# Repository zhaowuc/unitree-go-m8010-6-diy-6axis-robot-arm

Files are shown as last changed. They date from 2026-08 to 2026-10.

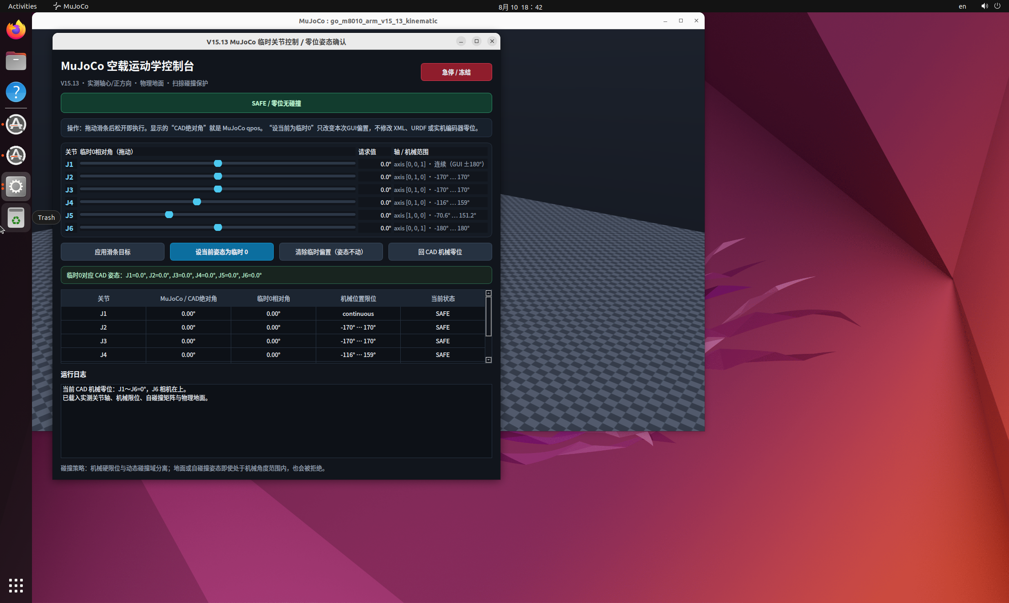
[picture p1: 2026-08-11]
mujoco_kinematic_v1/previews/gui_vm_desktop.png

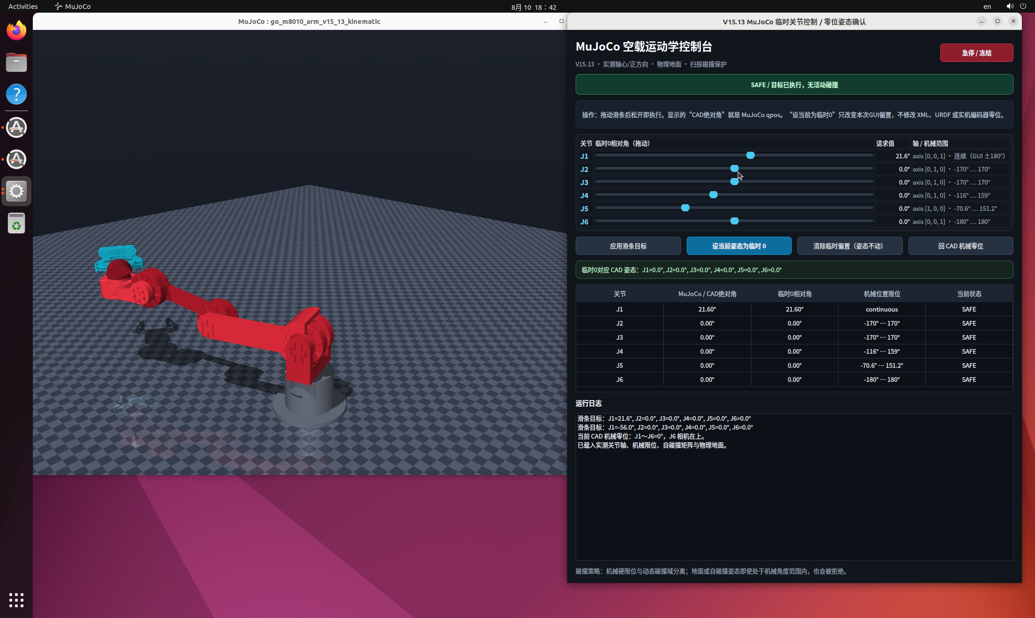
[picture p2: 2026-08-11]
mujoco_kinematic_v1/previews/gui_vm_desktop_arranged.png

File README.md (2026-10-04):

# 基于宇树go-m8010-6关节电机的自组6轴机械臂

这是 GO-M8010-6 + DM-G6220 六自由度机械臂的长期主工程。当前主线为 V15.13，仓库保留机械设计、几何与碰撞验收、仿真集成资产以及后续 ROS 2 / MoveIt 2 开发所需的源文件。

## 主要内容

- FreeCAD 完整机械装配、刚性 Link 拆分工程和 STEP/STL 模型；
- J1～J6 真实关节中心、轴向、零位与机械位置限位定义；
- MuJoCo 空载运动学模型、物理网格地面、自碰撞守卫和临时关节控制界面；
- ROS 2 工作区、URDF/Xacro、视觉与碰撞网格；
- MoveIt 2 配置、关节限位和自碰撞策略；
- 装配预览、实物运动证据、几何/碰撞 QA 报告和复现工具。

## 机械与运动学约定

- 软件运动学保持六个机械自由度：`J1`～`J6`。
- `J2` 是一个机械自由度，由两台镜像安装的 GO-M8010-6 共同驱动；两台电机不是两个独立运动学关节，软件中仍只有一个 `J2`。
- `world -> base_link -> J1 -> link1 -> J2 -> link2 -> J3 -> link3 -> J4 -> link4 -> J5 -> link5 -> J6 -> link6 -> fixed -> gripper`。
- `tool_reference` 是 J6 输出/夹爪安装中心。
- `tcp_nominal` 是 `ClosureAngle=0°` 时左右硅胶有效夹持面面积质心的中点，位于 gripper 局部坐标：

  ```text
  [-0.001187726400, 0.000060729026, 0.092493513872] m
  ```

  当前只在 MuJoCo 中作为固定名义参考点使用；动态 TCP、ROS TF 和 MoveIt TCP 尚未实现。

## 目录

- `机械臂完整装配_六轴_相机上置机械零位_深度复核_v15_13.FCStd`：当前完整装配。
- `机械臂完整装配_六轴_刚性Link拆分_v15_13.FCStd`：刚性 Link 拆分工程。
- `mujoco_kinematic_v1/`：当前可运行的 MuJoCo 空载运动学版本。
- `rigid_links_v15_13/`：ROS 2 / MuJoCo 刚性 Link 网格与导出定义。
- `完整工程_V15_13_交付/ros2_ws/`：ROS 2、URDF/Xacro 与 MoveIt 2 工程。
- `完整工程_V15_13_交付/source_models/`：夹爪和相机源模型。
- `evidence/`、`装配预览图/`、`三视图资产_world/`：验收证据与展示资产。
- `完整工程_V15_13_交付/tools/`、`mujoco_kinematic_v1/windows_export_tools/`：构建、导出和验证工具。

## 当前工程边界

当前 MuJoCo 版本首先保证外形、尺寸、相对位置、J1～J6 运动学、机械限位和自碰撞关系。质量、质心、惯量、速度、力矩、阻尼、摩擦和负载参数仍需依据实测数据完善，不应把现有占位值用于最终动力学或实机力矩控制。

后续计划包括重力补偿、动态 TCP、ROS 2 控制链、MoveIt 2 规划完善以及 Gemini Pro 视觉抓取。

## 大型文件

FCStd、STEP/STP、STL、OBJ、DAE、GLB、MP4 等机械与媒体资产由 Git LFS 管理。克隆后请确保已安装 Git LFS，并执行：

```bash
git lfs install
git lfs pull
```

## 开源许可证

本项目采用 [MIT 许可证](LICENSE)。第三方模型、依赖和素材遵循各自的许可证。

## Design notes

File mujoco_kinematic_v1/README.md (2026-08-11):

# V15.13 MuJoCo 空载运动学版

本版只验收四项：

1. `base_link`、`link1`～`link6`、`gripper` 的外形、尺寸和零位相对位置；
2. J1～J6 真实旋转中心；
3. J1～J6 轴向与右手法则正方向；
4. 机械位置限位、非相邻刚体自碰撞和物理地面碰撞。

主模型：`go_m8010_arm_v15_13_kinematic.xml`

拓扑固定为：

`world -> base_link -> J1 -> link1 -> J2 -> link2 -> J3 -> link3 -> J4 -> link4 -> J5 -> link5 -> J6 -> link6 -> fixed -> gripper`

J6 为有限旋转 `[-π,+π]`，`J6=0` 时 Gemini Pro 相机在上。夹爪在这个六轴首版中冻结于已验证的零位，以 fixed body 连接到 `link6`。

## 最终验证结果

- MuJoCo：`3.11.0`，模型可实际编译；
- 拓扑：`nq=6`、`nv=6`，J1～J6 顺序正确；
- Link 零位位姿、关节中心、轴向和 `+0.5°` 右手法则见证点全部通过；
- 视觉网格未减面，原三角面集保留；仅为 MuJoCo 单 STL `200,000` 面上限分成 45 个块；
- 24 个 FreeCAD 审计碰撞代理生成 961 个米制凸体；
- 保存零位的完整 231 对运行时矩阵无碰撞；
- 原 503 姿态“V15.13 末端变更相关碰撞对”回归完全一致；随机 150 位姿仍仅索引 `43, 73, 75, 83, 87` 碰撞，与 FreeCAD/VTK 基准一致；
- 新增全运行时碰撞对的逐轴 5° 深度扫描（386 点）：J1、J6 全清空；J2 有 31 个对地禁用点；J3 有 29 个对地、9 个自碰撞点（35 个姿态并集）；J4 有 12 个对地、1 个自碰撞点；J5 有 2 个自碰撞点；这些点均被运行时守卫及扫掠路径检查 fail-closed 拦截；
- 网格地面位于 `Z=-0.090 m`，由 `base_link` 最低支承面精确导出。固定底座不与地面求解，所有运动 Link 启用地面碰撞；
- 完整报告：`QA_MUJOCO_V15_13_空载运动学版.json`。
- 逐轴深度报告：`QA_MUJOCO_V15_13_逐轴运动语义与地面复核.json`。

Link 局部包围尺寸（mm）：

| Link | X | Y | Z |
|---|---:|---:|---:|
| base_link | 176.921 | 176.866 | 100.000 |
| link1 | 96.500 | 137.600 | 149.190 |
| link2 | 307.096 | 99.500 | 115.901 |
| link3 | 299.261 | 52.500 | 148.876 |
| link4 | 60.828 | 97.000 | 176.265 |
| link5 | 70.000 | 70.000 | 127.527 |
| link6 | 34.992 | 35.001 | 1.000 |
| gripper | 107.129 | 133.135 | 123.402 |

## Ubuntu 22.04 执行

```bash
source /home/codex/mujoco_arm_env/bin/activate
python build_model.py
python validate_model.py
python validate_joint_motion_semantics.py
MUJOCO_GL=egl python render_previews.py
```

交互查看：

```bash
DISPLAY=:1 XAUTHORITY=/run/user/1000/gdm/Xauthority \
  /home/codex/mujoco_arm_env/bin/python launch_viewer.py
```

单点限位/碰撞检查（角度制 J1～J6）：

```bash
python kinematic_guard.py 0 0 0 0 0 0
```

`KinematicGuard.check_swept_deg()` 以默认最大 `0.25°` 插值步长检查一段运动。

临时滑条 GUI（会同时打开可用鼠标旋转视角的 MuJoCo 窗口）：

```bash
DISPLAY=:1 XAUTHORITY=/run/user/1000/gdm/Xauthority MUJOCO_GL=glfw \
  /home/codex/mujoco_arm_env/bin/python temporary_joint_gui.py
```

GUI 中显示两套角度：

- `MuJoCo / CAD绝对角`：模型真实 `qpos`，以已核验 CAD 机械零位为 0；
- `临时0相对角`：本次 GUI 会话的滑条偏置。

先用滑条移动到安全姿态，再点“保存当前姿态为启动 0”，界面会明确显示该 GUI 启动 0 对应的六个 CAD 绝对角，并写入 `gui_default_zero.json`。再次打开 GUI 时，模型直接恢复到该姿态，六个相对滑条均为 0°。该操作不修改 MJCF、URDF、CAD 机械零位或实机编码器零位；“回 CAD 机械零位”只影响当前会话，不删除已保存的 GUI 启动 0。地面、自碰撞、机械限位或穿越不安全中间姿态时，目标会被拒绝并保持上一安全姿态。

当前几何精校后的 GUI 启动 0（CAD 绝对角）：`J1=-135.0°、J2=150.0°、J3=-74.402070913°、J4=-90.0°、J5=45.0°、J6=0.713491710°`。该解保留规整的 J1/J2/J4/J5，仅根据真实 J3、J4 轴心求解 J3，使 J3→J4 中心线竖直；再根据 Gemini Pro 碰撞代理的 102.896 mm 长轴求解 J6，使相机长边与物理地面平行，同时保持既有相机俯仰/观看分支。复算脚本为 `calibrate_gui_zero.py`，完整残差、限位、碰撞及扫掠结果见 `QA_MUJOCO_V15_13_GUI零位几何校准.json`。

如果从 FreeCAD 原始网格全量重建，再执行：

```bash
python prepare_assets.py
python prepare_visual_chunks.py
python build_model.py
python validate_model.py
python validate_joint_motion_semantics.py
```

`V15_13_自碰撞对矩阵契约.json` 是运行时/MoveIt ACM 的对级契约；`kinematic_guard.py` 会仅上报契约中有效的物理对，忽略同刚体、轴承座和设计接触。

## 物理边界

当前 `inertial` 仅为 MuJoCo 编译所需的数值占位，不是实测质量/质心/惯量。未实测速度、力矩、阻尼、摩擦及负载；不得将本版用于动力学、力矩控制或实机参数整定。

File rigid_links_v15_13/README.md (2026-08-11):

# V15 刚性 Link 拆分

本目录不是“整机一个 STL”。主机械臂按以下刚体链导出：

`world -> base_link -> J1 -> link1 -> J2 -> link2 -> J3 -> link3 -> J4 -> link4 -> J5 -> link5 -> J6 -> link6 -> fixed -> gripper`

- `visual/*.stl` 与 `collision/*.stl` 均在各自 Link 局部坐标系中，STL 数值单位为 mm。
- ROS 2 / MuJoCo 使用时 mesh scale 为 `0.001 0.001 0.001`。
- 每颗螺丝、垫圈和固定支架已经并入随动刚体，没有生成独立 Link。
- J1/J2 的完整 GO-M8010 STEP 已按工程中审计过的 BRep 固体编号拆成定子、输出转子和中性 B6808 显示件，未按外观猜测。
- `gripper.stl` 只包含与连接件、舵机壳体和固定框架相对静止的静态部分。
- 夹爪六个会相对运动的刚体位于 `gripper_internal_zero_reference/`；这些文件共用 `gripper` 零位坐标，仅用于后续建立夹爪内部关节，不得重新焊成一个刚体。
- `gripper_complete_zero_reference.stl` 只是零位总览，不能作为单个 URDF/MuJoCo 刚体。
- 质量、质心、惯量、速度/力矩上限、MuJoCo 设计接触排除和 tool0/TCP 尚无实测数据，未填写猜测值。

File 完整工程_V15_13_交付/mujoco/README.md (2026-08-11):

# MuJoCo V15.13 staging

关节树、轴、原点、J2～J6 位置限位和 visual/collision 网格已写入模板。J6 为 `hinge`，`ref=0` 时相机在上，`range=-π +π`。

模板中的质量、质心、完整惯量张量和摩擦参数均为 `__...__` 占位符，必须由实测/标定值替换；没有替换前不是可运行的动力学模型。不要让 MuJoCo 依据高细节网格默认密度猜惯量。组合动作仍需使用碰撞检测，因为独立关节限位的笛卡尔积包含自碰撞姿态。

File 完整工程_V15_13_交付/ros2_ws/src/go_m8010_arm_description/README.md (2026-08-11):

# go_m8010_arm_description V15.13

几何、真实关节轴、关节原点、零位和位置限位已经复核。J6 在 `0°` 时相机位于上侧，位置限位为 `[-π,+π]`。

`j*_effort_nm` 与 `j*_velocity_rad_s` 默认值为 `0`，这是故障安全占位，不是电机参数。完成电机、减速器、热约束与线束实测后必须显式传入；质量、质心和惯量未测量，因此 URDF 暂不含 inertial，不能作为最终动力学模型。

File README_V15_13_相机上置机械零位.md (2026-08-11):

# V15.13 相机上置 J6 机械零位

主装配：`机械臂完整装配_六轴_相机上置机械零位_深度复核_v15_13.FCStd`

本版以用户提供的实物活动视频为装配方向证据。V15.12 的 DM-G6220 输出法兰、蓝色连接件、反转夹爪和 Gemini 相机之间的相对装配全部保持不变；完整 J6 输出刚体仅绕已测量的真实 J6 轴换钟向 180°，并把相机位于上方的姿态重新定义为 `J6=0°`。

J6 仍为有限转动关节，范围 `-180° .. +180°`，不是把保存角度停在 180° 边界。ROS2 与 MuJoCo 的 link6 零位坐标系已同步换钟向，详见 `V15_13_真实关节轴与相机上置零位.json`。

相机碰撞采用两个保守包络，分别包住相机 STEP 中的两个实体；显示 STEP 不重复参与碰撞。完整整机碰撞扫描、连续守卫和刚性 Link 导出由同目录后续 QA 文件给出。

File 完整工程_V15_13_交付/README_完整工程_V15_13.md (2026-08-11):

# 机械臂完整工程 V15.13

## 最终状态

- J6 的真实机械零位已重定标：`J6=0°` 时 Gemini Pro 相机位于上侧。
- 未旋转连接件相对 DM-G6220 输出法兰的装配关系；仅把完整 J6 输出刚体的物理时钟位重定义为零位。
- J6 保留 `-180°..+180°`，没有把 180° 边界伪装成零位。
- 夹爪保持绕自身安装轴反转后的正确方向，未增加转接片。
- 相机使用模型自带铰链耳直接贴装连接件。

## 深度验收

- 保存零位：无碰撞。
- 全零位矩阵：231 对有效碰撞对。
- 动态扫描：503 个姿态、14,860 次窄相检测。
- J1～J6 独立全限位扫描均通过；J5/J6 网格和 32 个组合边界角均通过。
- 150 个确定性随机六轴组合中发现 5 个真实自碰撞姿态，因此完整可行域不是各关节限位的简单笛卡尔积。
- 连续碰撞守卫回归通过：J6 以 0.25° 扫掠 0°→1°→0°，且 +181° 被拒绝。

## 使用边界

位置限位、真实轴、零位、刚性 Link、visual/collision 网格可用于 ROS2、MoveIt 和 MuJoCo 的几何集成。速度、力矩、质量、质心、惯量、摩擦、TCP 和 J1 线束累计圈数没有可靠实测值，工程中没有猜填。ROS2 的速度/力矩默认 0（故障安全占位）；MuJoCo 模板保留显式占位符，替换实测值前不得当作最终动力学模型。

实机或轨迹规划必须使用连续碰撞检测，不能只做端点检查。

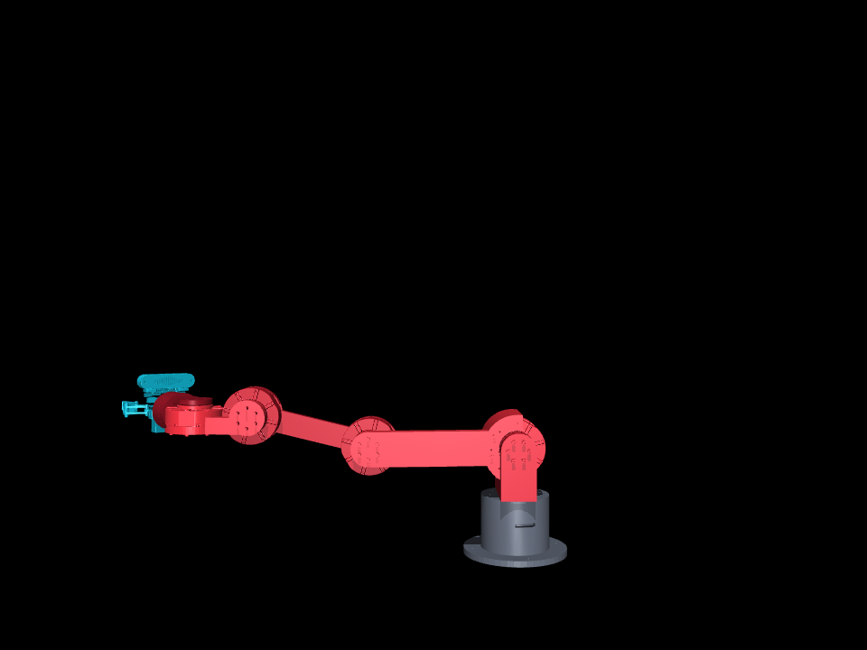
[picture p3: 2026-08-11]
mujoco_kinematic_v1/previews/zero_side.png

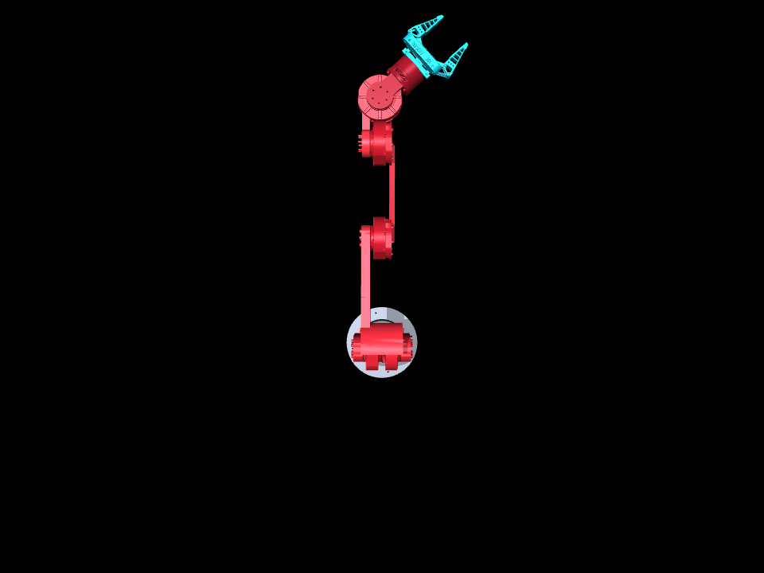
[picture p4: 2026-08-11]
mujoco_kinematic_v1/previews/zero_top.png

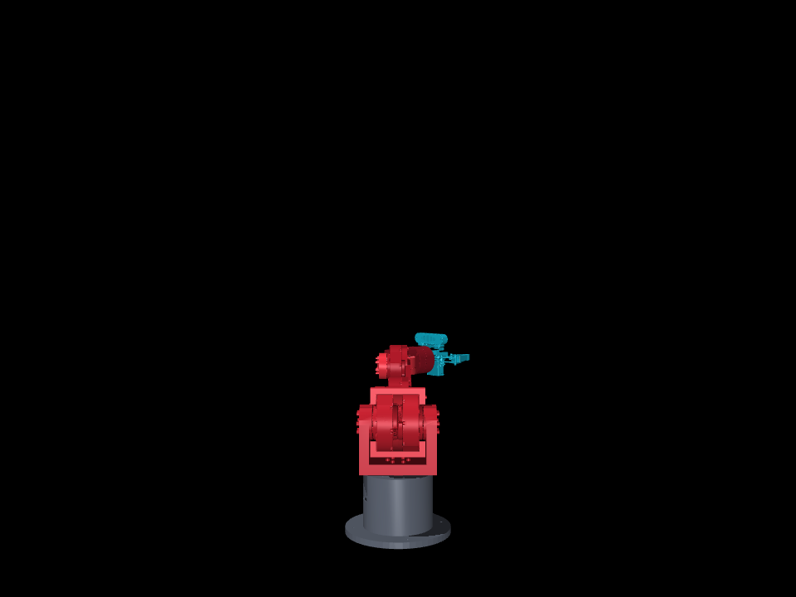
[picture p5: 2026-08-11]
mujoco_kinematic_v1/previews/zero_front.png

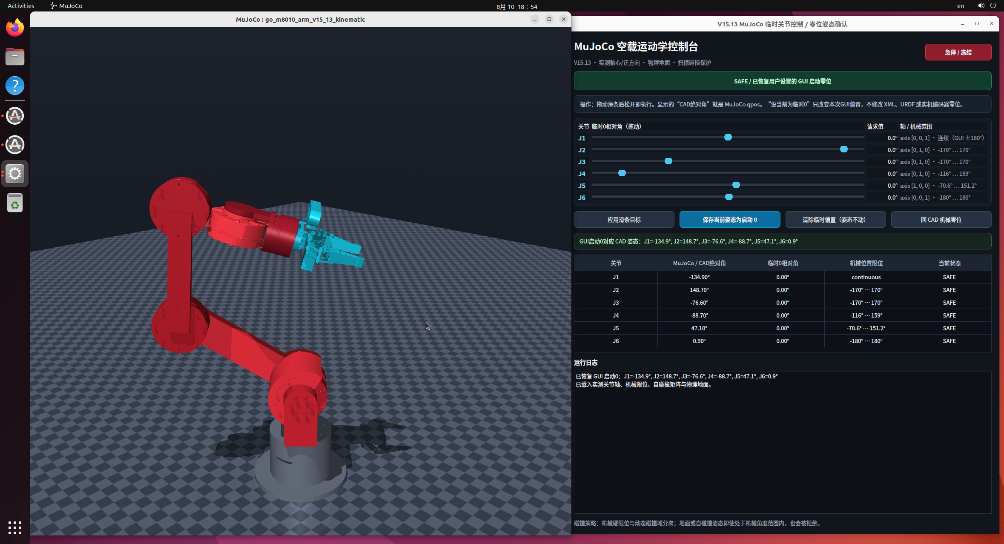
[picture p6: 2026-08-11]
mujoco_kinematic_v1/previews/restored_gui_default_zero.png

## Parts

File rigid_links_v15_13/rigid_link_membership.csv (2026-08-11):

owner | geometry_role | token | source_object | derivation | urdf_link_count
base_link | visual | Support_Foot | Support_Foot | direct_object | 1
base_link | visual | Upper_Base | Upper_Base | direct_object | 1
base_link | visual | derived:J1_GO_M8010_stator | Joint_Motor_GO_M8010_6 | stator | 1
base_link | collision | Support_Foot | Support_Foot | direct_object | 1
base_link | collision | Upper_Base | Upper_Base | direct_object | 1
base_link | collision | J1_Fixed_Collision_Proxy | J1_Fixed_Collision_Proxy | direct_object | 1
base_link | collision | derived:J1_GO_M8010_stator | Joint_Motor_GO_M8010_6 | stator | 1
link1 | visual | J1_Axial_Compensation_Spacer | J1_Axial_Compensation_Spacer | direct_object | 1
link1 | visual | V6_Shoulder_Official_M4 | V6_Shoulder_Official_M4 | direct_object | 1
link1 | visual | M4_Screw_01 | M4_Screw_01 | direct_object | 1
link1 | visual | M4_Screw_02 | M4_Screw_02 | direct_object | 1
link1 | visual | M4_Screw_03 | M4_Screw_03 | direct_object | 1
link1 | visual | M4_Screw_04 | M4_Screw_04 | direct_object | 1
link1 | visual | M4_Screw_05 | M4_Screw_05 | direct_object | 1
link1 | visual | M4_Screw_06 | M4_Screw_06 | direct_object | 1
link1 | visual | J2_Left_M4x30_Screw_01 | J2_Left_M4x30_Screw_01 | direct_object | 1
link1 | visual | J2_Left_M4x30_Screw_02 | J2_Left_M4x30_Screw_02 | direct_object | 1
link1 | visual | J2_Left_M4x30_Screw_03 | J2_Left_M4x30_Screw_03 | direct_object | 1
link1 | visual | J2_Left_M4x30_Screw_04 | J2_Left_M4x30_Screw_04 | direct_object | 1
link1 | visual | J2_Left_M4x30_Screw_05 | J2_Left_M4x30_Screw_05 | direct_object | 1
link1 | visual | J2_Left_M4x30_Screw_06 | J2_Left_M4x30_Screw_06 | direct_object | 1
link1 | visual | J2_Left_M4_Washer_01 | J2_Left_M4_Washer_01 | direct_object | 1
link1 | visual | J2_Left_M4_Washer_02 | J2_Left_M4_Washer_02 | direct_object | 1
link1 | visual | J2_Left_M4_Washer_03 | J2_Left_M4_Washer_03 | direct_object | 1
link1 | visual | J2_Left_M4_Washer_04 | J2_Left_M4_Washer_04 | direct_object | 1
link1 | visual | J2_Left_M4_Washer_05 | J2_Left_M4_Washer_05 | direct_object | 1
link1 | visual | J2_Left_M4_Washer_06 | J2_Left_M4_Washer_06 | direct_object | 1
link1 | visual | J2_Right_M4x30_Screw_01 | J2_Right_M4x30_Screw_01 | direct_object | 1
link1 | visual | J2_Right_M4x30_Screw_02 | J2_Right_M4x30_Screw_02 | direct_object | 1
link1 | visual | J2_Right_M4x30_Screw_03 | J2_Right_M4x30_Screw_03 | direct_object | 1
link1 | visual | J2_Right_M4x30_Screw_04 | J2_Right_M4x30_Screw_04 | direct_object | 1
link1 | visual | J2_Right_M4x30_Screw_05 | J2_Right_M4x30_Screw_05 | direct_object | 1
link1 | visual | J2_Right_M4x30_Screw_06 | J2_Right_M4x30_Screw_06 | direct_object | 1
link1 | visual | J2_Right_M4_Washer_01 | J2_Right_M4_Washer_01 | direct_object | 1
link1 | visual | J2_Right_M4_Washer_02 | J2_Right_M4_Washer_02 | direct_object | 1
link1 | visual | J2_Right_M4_Washer_03 | J2_Right_M4_Washer_03 | direct_object | 1
link1 | visual | J2_Right_M4_Washer_04 | J2_Right_M4_Washer_04 | direct_object | 1
link1 | visual | J2_Right_M4_Washer_05 | J2_Right_M4_Washer_05 | direct_object | 1
link1 | visual | J2_Right_M4_Washer_06 | J2_Right_M4_Washer_06 | direct_object | 1
link1 | visual | derived:J1_GO_M8010_output | Joint_Motor_GO_M8010_6 | output | 1
link1 | visual | derived:J1_GO_M8010_neutral | Joint_Motor_GO_M8010_6 | neutral | 1
link1 | visual | derived:J2A_GO_M8010_stator | J2_Left_Joint_Motor_GO_M8010_6 | stator | 1
link1 | visual | derived:J2B_GO_M8010_stator | J2_Right_Joint_Motor_GO_M8010_6 | stator | 1
link1 | collision | J1_Moving_Collision_Proxy | J1_Moving_Collision_Proxy | direct_object | 1
link1 | collision | J1_Output_Rotor_Proxy | J1_Output_Rotor_Proxy | direct_object | 1
link2 | visual | UpperArm_A_SleeveSide_PrintPart | UpperArm_A_SleeveSide_PrintPart | direct_object | 1
link2 | visual | UpperArm_B_Distal_PrintPart | UpperArm_B_Distal_PrintPart | direct_object | 1
link2 | visual | J3_Output_Rotor_STEP_Display | J3_Output_Rotor_STEP_Display | direct_object | 1
link2 | visual | J3_B6808_Bearing_Neutral_STEP_Display | J3_B6808_Bearing_Neutral_STEP_Display | direct_object | 1
link2 | visual | UpperArm_M35_Bottom_01 | UpperArm_M35_Bottom_01 | direct_object | 1
link2 | visual | UpperArm_M35_Bottom_02 | UpperArm_M35_Bottom_02 | direct_object | 1
link2 | visual | UpperArm_M35_Bottom_03 | UpperArm_M35_Bottom_03 | direct_object | 1
link2 | visual | UpperArm_M35_Top_01 | UpperArm_M35_Top_01 | direct_object | 1
link2 | visual | UpperArm_M35_Top_02 | UpperArm_M35_Top_02 | direct_object | 1
link2 | visual | UpperArm_M35_Top_03 | UpperArm_M35_Top_03 | direct_object | 1
link2 | visual | J3_Output_M4_Screw_01 | J3_Output_M4_Screw_01 | direct_object | 1
link2 | visual | J3_Output_M4_Screw_02 | J3_Output_M4_Screw_02 | direct_object | 1
link2 | visual | J3_Output_M4_Screw_03 | J3_Output_M4_Screw_03 | direct_object | 1
link2 | visual | J3_Output_M4_Screw_04 | J3_Output_M4_Screw_04 | direct_object | 1
link2 | visual | J3_Output_M4_Screw_05 | J3_Output_M4_Screw_05 | direct_object | 1
link2 | visual | J3_Output_M4_Screw_06 | J3_Output_M4_Screw_06 | direct_object | 1
link2 | visual | derived:J2A_GO_M8010_output | J2_Left_Joint_Motor_GO_M8010_6 | output | 1
link2 | visual | derived:J2A_GO_M8010_neutral | J2_Left_Joint_Motor_GO_M8010_6 | neutral | 1
link2 | visual | derived:J2B_GO_M8010_output | J2_Right_Joint_Motor_GO_M8010_6 | output | 1
link2 | visual | derived:J2B_GO_M8010_neutral | J2_Right_Joint_Motor_GO_M8010_6 | neutral | 1
link2 | collision | UpperArm_Full_Collision_Proxy | UpperArm_Full_Collision_Proxy | direct_object | 1
link2 | collision | J3_Output_Flange_Proxy | J3_Output_Flange_Proxy | direct_object | 1
link2 | collision | derived:J2A_GO_M8010_output_collision | J2_Left_Joint_Motor_GO_M8010_6 | output_collision | 1
link2 | collision | derived:J2B_GO_M8010_output_collision | J2_Right_Joint_Motor_GO_M8010_6 | output_collision | 1
link3 | visual | J3_Motor_Stator_STEP_Display | J3_Motor_Stator_STEP_Display | direct_object | 1
link3 | visual | Forearm_v3_HighDetail_Display | Forearm_v3_HighDetail_Display | direct_object | 1
link3 | visual | J4_Motor_Stator_STEP_Display | J4_Motor_Stator_STEP_Display | direct_object | 1
link3 | visual | Forearm_J3_M35_Screw_01 | Forearm_J3_M35_Screw_01 | direct_object | 1
link3 | visual | Forearm_J3_M35_Screw_02 | Forearm_J3_M35_Screw_02 | direct_object | 1
link3 | visual | Forearm_J3_M35_Screw_03 | Forearm_J3_M35_Screw_03 | direct_object | 1
link3 | visual | Forearm_J3_M35_Screw_04 | Forearm_J3_M35_Screw_04 | direct_object | 1
link3 | visual | Forearm_J3_M35_Screw_05 | Forearm_J3_M35_Screw_05 | direct_object | 1
link3 | visual | Forearm_J3_M35_Screw_06 | Forearm_J3_M35_Screw_06 | direct_object | 1
link3 | visual | Forearm_J4_M35_Screw_01 | Forearm_J4_M35_Screw_01 | direct_object | 1
link3 | visual | Forearm_J4_M35_Screw_02 | Forearm_J4_M35_Screw_02 | direct_object | 1
link3 | visual | Forearm_J4_M35_Screw_03 | Forearm_J4_M35_Screw_03 | direct_object | 1
link3 | visual | Forearm_J4_M35_Screw_04 | Forearm_J4_M35_Screw_04 | direct_object | 1
link3 | visual | Forearm_J4_M35_Screw_05 | Forearm_J4_M35_Screw_05 | direct_object | 1
link3 | visual | Forearm_J4_M35_Screw_06 | Forearm_J4_M35_Screw_06 | direct_object | 1
link3 | collision | J3_Motor_Stator_Collision_Proxy | J3_Motor_Stator_Collision_Proxy | direct_object | 1
link3 | collision | Forearm_Collision_Proxy | Forearm_Collision_Proxy | direct_object | 1
link3 | collision | J4_Motor_Stator_Collision_Proxy | J4_Motor_Stator_Collision_Proxy | direct_object | 1
link4 | visual | J4_Output_Rotor_STEP_Display | J4_Output_Rotor_STEP_Display | direct_object | 1
link4 | visual | J4_B6808_Bearing_Neutral_STEP_Display | J4_B6808_Bearing_Neutral_STEP_Display | direct_object | 1
link4 | visual | Wrist_Prelink_v1_HighDetail_Display | Wrist_Prelink_v1_HighDetail_Display | direct_object | 1
link4 | visual | J5_Motor_Stator_STEP_Display | J5_Motor_Stator_STEP_Display | direct_object | 1
link4 | visual | J4_Output_M4_Screw_01 | J4_Output_M4_Screw_01 | direct_object | 1
link4 | visual | J4_Output_M4_Screw_02 | J4_Output_M4_Screw_02 | direct_object | 1
link4 | visual | J4_Output_M4_Screw_03 | J4_Output_M4_Screw_03 | direct_object | 1
link4 | visual | J4_Output_M4_Screw_04 | J4_Output_M4_Screw_04 | direct_object | 1
link4 | visual | J4_Output_M4_Screw_05 | J4_Output_M4_Screw_05 | direct_object | 1
link4 | visual | J4_Output_M4_Screw_06 | J4_Output_M4_Screw_06 | direct_object | 1
link4 | visual | Wrist_Prelink_J5_M35_Screw_01 | Wrist_Prelink_J5_M35_Screw_01 | direct_object | 1
link4 | visual | Wrist_Prelink_J5_M35_Screw_02 | Wrist_Prelink_J5_M35_Screw_02 | direct_object | 1
link4 | visual | Wrist_Prelink_J5_M35_Screw_03 | Wrist_Prelink_J5_M35_Screw_03 | direct_object | 1
link4 | visual | Wrist_Prelink_J5_M35_Screw_04 | Wrist_Prelink_J5_M35_Screw_04 | direct_object | 1
link4 | visual | Wrist_Prelink_J5_M35_Screw_05 | Wrist_Prelink_J5_M35_Screw_05 | direct_object | 1
link4 | visual | Wrist_Prelink_J5_M35_Screw_06 | Wrist_Prelink_J5_M35_Screw_06 | direct_object | 1
link4 | collision | J4_Output_Flange_Collision_Proxy | J4_Output_Flange_Collision_Proxy | direct_object | 1
link4 | collision | Wrist_Prelink_Collision_Proxy | Wrist_Prelink_Collision_Proxy | direct_object | 1
link4 | collision | J5_Motor_Stator_Collision_Proxy | J5_Motor_Stator_Collision_Proxy | direct_object | 1
link5 | visual | J5_Output_Rotor_STEP_Display | J5_Output_Rotor_STEP_Display | direct_object | 1
link5 | visual | J5_B6808_Bearing_Neutral_STEP_Display | J5_B6808_Bearing_Neutral_STEP_Display | direct_object | 1
link5 | visual | J5_to_Damiao_J6_Adapter_STL_Display | J5_to_Damiao_J6_Adapter_STL_Display | direct_object | 1
link5 | visual | J6_DM_G6220_Stator_STEP_Display | J6_DM_G6220_Stator_STEP_Display | direct_object | 1
link5 | visual | Adapter_DM_G6220_M4x12_Screw_01 | Adapter_DM_G6220_M4x12_Screw_01 | direct_object | 1
link5 | visual | Adapter_DM_G6220_M4x12_Screw_02 | Adapter_DM_G6220_M4x12_Screw_02 | direct_object | 1
link5 | visual | Adapter_DM_G6220_M4x12_Screw_03 | Adapter_DM_G6220_M4x12_Screw_03 | direct_object | 1
link5 | collision | J5_Output_Flange_Collision_Proxy | J5_Output_Flange_Collision_Proxy | direct_object | 1
link5 | collision | J5_to_Damiao_J6_Adapter_Collision_Proxy | J5_to_Damiao_J6_Adapter_Collision_Proxy | direct_object | 1
link5 | collision | J6_DM_G6220_Stator_Collision_Proxy | J6_DM_G6220_Stator_Collision_Proxy | direct_object | 1
link6 | visual | J6_DM_G6220_Output_Rotor_STEP_Display | J6_DM_G6220_Output_Rotor_STEP_Display | direct_object | 1
link6 | collision | J6_DM_G6220_Output_Rotor_Collision_Proxy | J6_DM_G6220_Output_Rotor_Collision_Proxy | direct_object | 1
gripper | visual | J6_Gripper_Connector_STEP_Display | J6_Gripper_Connector_STEP_Display | direct_object | 1
gripper | visual | Gripper_Servo_STEP_Display | Gripper_Servo_STEP_Display | direct_object | 1
gripper | visual | Gripper_Fixed_Frame_STEP_Display | Gripper_Fixed_Frame_STEP_Display | direct_object | 1
gripper | visual | Gemini_Pro_Camera_STEP_Display | Gemini_Pro_Camera_STEP_Display | direct_object | 1
gripper | visual | Gripper_Hardware_03 | Gripper_Hardware_03 | direct_object | 1
gripper | visual | Gripper_Hardware_04 | Gripper_Hardware_04 | direct_object | 1
gripper | visual | Gripper_Hardware_07 | Gripper_Hardware_07 | direct_object | 1
gripper | visual | Gripper_Hardware_08 | Gripper_Hardware_08 | direct_object | 1
gripper | visual | Gripper_Hardware_09 | Gripper_Hardware_09 | direct_object | 1
gripper | visual | Gripper_Hardware_10 | Gripper_Hardware_10 | direct_object | 1
gripper | visual | Gripper_Hardware_15 | Gripper_Hardware_15 | direct_object | 1
gripper | visual | Gripper_Hardware_16 | Gripper_Hardware_16 | direct_object | 1
gripper | visual | DM_G6220_Connector_M4x14_Screw_01 | DM_G6220_Connector_M4x14_Screw_01 | direct_object | 1
gripper | visual | DM_G6220_Connector_M4x14_Screw_02 | DM_G6220_Connector_M4x14_Screw_02 | direct_object | 1
gripper | visual | DM_G6220_Connector_M4x14_Screw_03 | DM_G6220_Connector_M4x14_Screw_03 | direct_object | 1
gripper | visual | DM_G6220_Connector_M4x14_Screw_04 | DM_G6220_Connector_M4x14_Screw_04 | direct_object | 1
gripper | visual | DM_G6220_Connector_M4x14_Screw_05 | DM_G6220_Connector_M4x14_Screw_05 | direct_object | 1
gripper | visual | DM_G6220_Connector_M4x14_Screw_06 | DM_G6220_Connector_M4x14_Screw_06 | direct_object | 1
gripper | visual | Gripper_Clevis_3DPrinted_M3x25_Screw_01 | Gripper_Clevis_3DPrinted_M3x25_Screw_01 | direct_object | 1
gripper | visual | Gripper_Clevis_3DPrinted_M3x25_Screw_02 | Gripper_Clevis_3DPrinted_M3x25_Screw_02 | direct_object | 1
gripper | collision | J6_Gripper_Connector_Collision_Proxy | J6_Gripper_Connector_Collision_Proxy | direct_object | 1
gripper | collision | Gripper_Fixed_Frame_Collision_Proxy | Gripper_Fixed_Frame_Collision_Proxy | direct_object | 1
gripper | collision | Gripper_Servo_Collision_Proxy | Gripper_Servo_Collision_Proxy | direct_object | 1
gripper | collision | Gemini_Pro_Camera_Collision_Proxy | Gemini_Pro_Camera_Collision_Proxy | direct_object | 1
gripper_internal:left_outer | visual | Gripper_Left_Outer_Link | Gripper_Left_Outer_Link | direct_object | 1
gripper_internal:left_outer | collision | Gripper_Left_Outer_Link | Gripper_Left_Outer_Link | direct_object_without_small_hardware | 1
gripper_internal:right_outer | visual | Gripper_Right_Outer_Link | Gripper_Right_Outer_Link | direct_object | 1
gripper_internal:right_outer | collision | Gripper_Right_Outer_Link | Gripper_Right_Outer_Link | direct_object_without_small_hardware | 1
gripper_internal:left_drive | visual | Gripper_Left_Drive_Link | Gripper_Left_Drive_Link | direct_object | 1
gripper_internal:left_drive | collision | Gripper_Left_Drive_Link | Gripper_Left_Drive_Link | direct_object_without_small_hardware | 1
gripper_internal:right_drive | visual | Gripper_Right_Drive_Link | Gripper_Right_Drive_Link | direct_object | 1
gripper_internal:right_drive | collision | Gripper_Right_Drive_Link | Gripper_Right_Drive_Link | direct_object_without_small_hardware | 1
gripper_internal:left_finger | visual | Gripper_Left_Finger | Gripper_Left_Finger | direct_object | 1
gripper_internal:left_finger | visual | Gripper_Hardware_02 | Gripper_Hardware_02 | direct_object | 1
gripper_internal:left_finger | visual | Gripper_Hardware_05 | Gripper_Hardware_05 | direct_object | 1
gripper_internal:left_finger | visual | Gripper_Hardware_11 | Gripper_Hardware_11 | direct_object | 1
gripper_internal:left_finger | visual | Gripper_Hardware_13 | Gripper_Hardware_13 | direct_object | 1
gripper_internal:left_finger | visual | Gripper_Hardware_14 | Gripper_Hardware_14 | direct_object | 1
gripper_internal:left_finger | collision | Gripper_Left_Finger | Gripper_Left_Finger | direct_object_without_small_hardware | 1
gripper_internal:right_finger | visual | Gripper_Right_Finger | Gripper_Right_Finger | direct_object | 1
gripper_internal:right_finger | visual | Gripper_Hardware_01 | Gripper_Hardware_01 | direct_object | 1
gripper_internal:right_finger | visual | Gripper_Hardware_06 | Gripper_Hardware_06 | direct_object | 1
gripper_internal:right_finger | visual | Gripper_Hardware_12 | Gripper_Hardware_12 | direct_object | 1
gripper_internal:right_finger | visual | Gripper_Hardware_17 | Gripper_Hardware_17 | direct_object | 1
gripper_internal:right_finger | visual | Gripper_Hardware_18 | Gripper_Hardware_18 | direct_object | 1
gripper_internal:right_finger | visual | Gripper_Hardware_19 | Gripper_Hardware_19 | direct_object | 1
gripper_internal:right_finger | collision | Gripper_Right_Finger | Gripper_Right_Finger | direct_object_without_small_hardware | 1

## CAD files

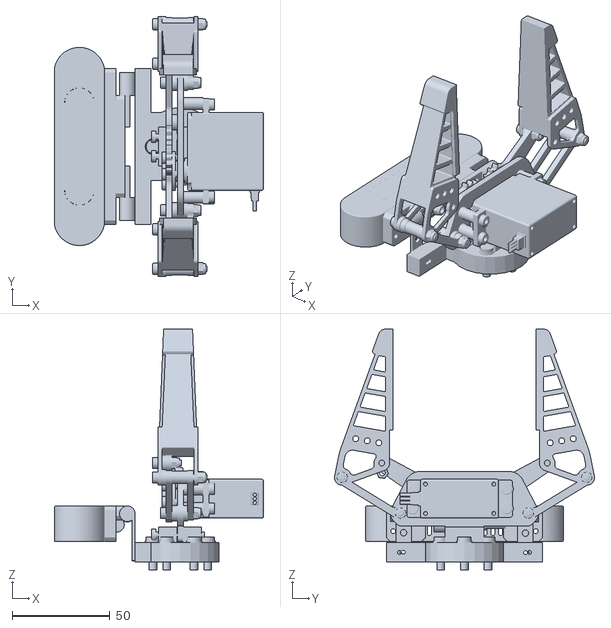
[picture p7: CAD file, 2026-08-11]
完整工程_V15_13_交付/references/gripper_internal_zero_reference/gripper_complete_zero_reference.stl
107.1 x 133.1 x 123.4

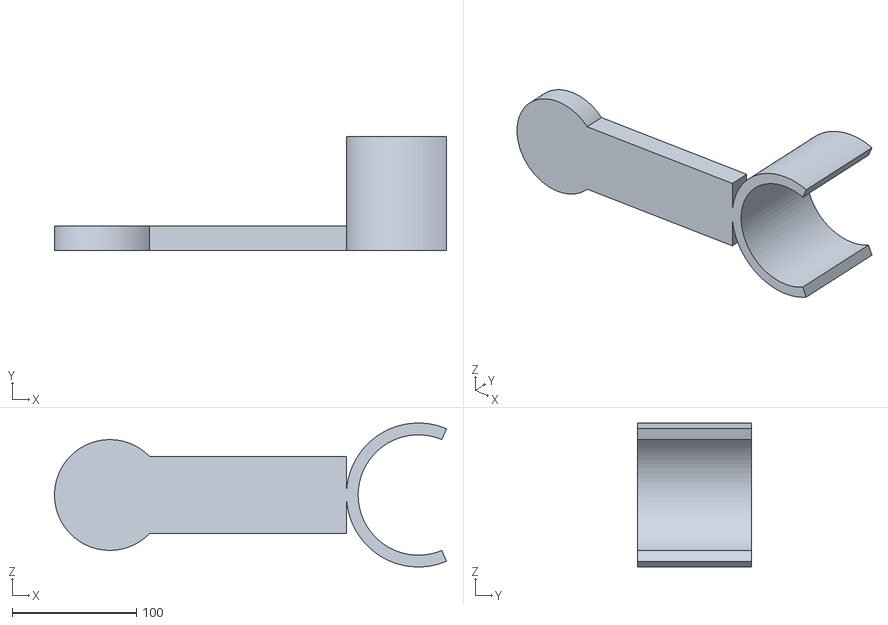
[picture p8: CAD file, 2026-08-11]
mujoco_kinematic_v1/meshes/collision_raw_mm/link2/01_UpperArm_Full_Collision_Proxy.stl
315.9 x 92.0 x 116.0

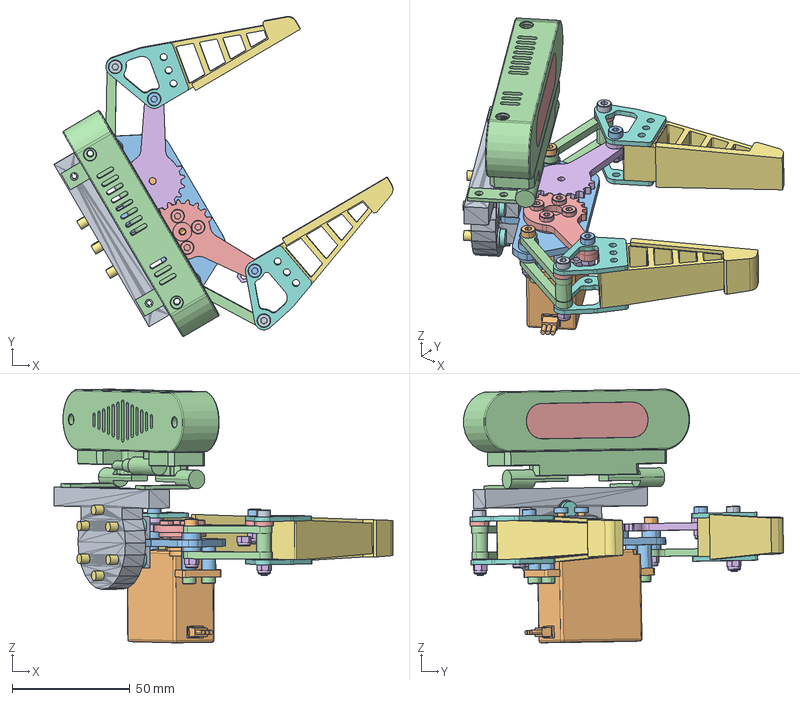
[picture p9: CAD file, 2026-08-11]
J6末端_相机上置机械零位_v15_13.step
144.3 x 136.2 x 108.0 mm

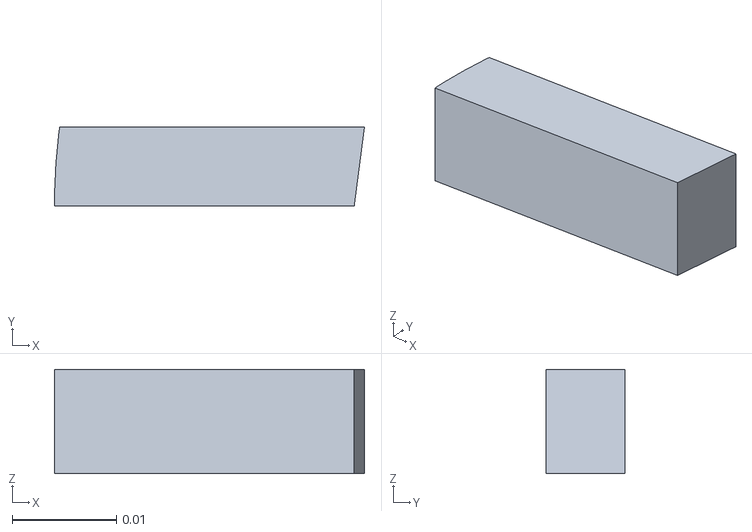
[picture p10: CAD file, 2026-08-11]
mujoco_kinematic_v1/meshes/collision_convex_m/base_link/007_m01_c01_p07.stl
0.0297 x 0.0076 x 0.01

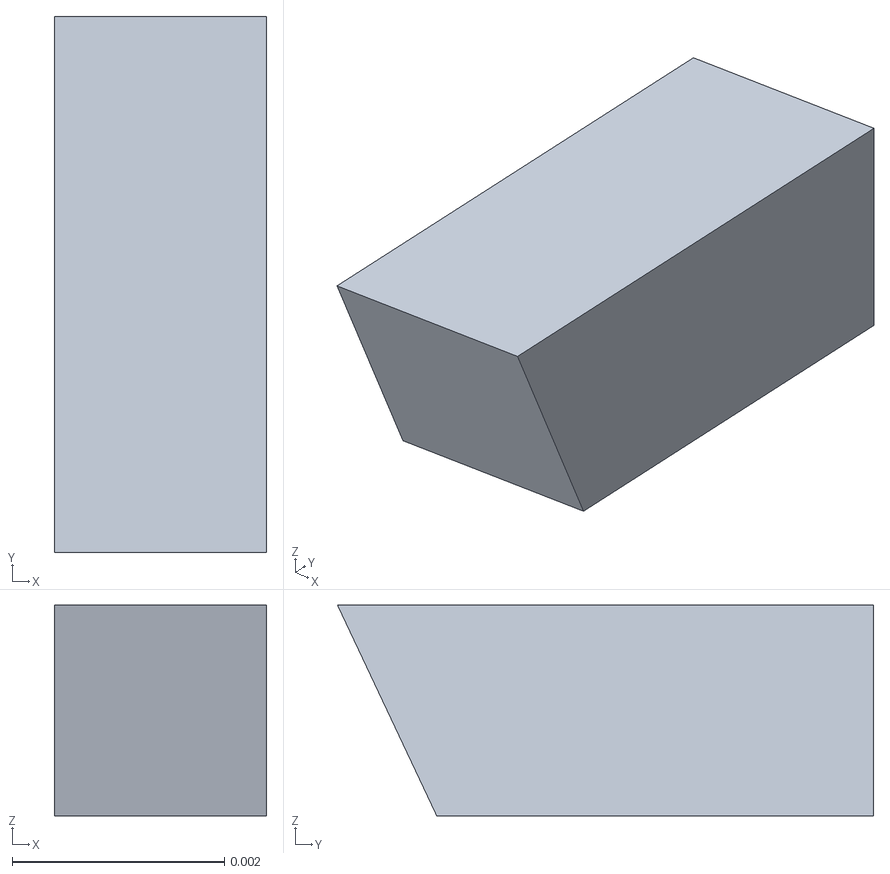
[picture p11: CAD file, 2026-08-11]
mujoco_kinematic_v1/meshes/collision_convex_m/gripper/432_m10_c03_p16.stl
0.002 x 0.00505 x 0.00199

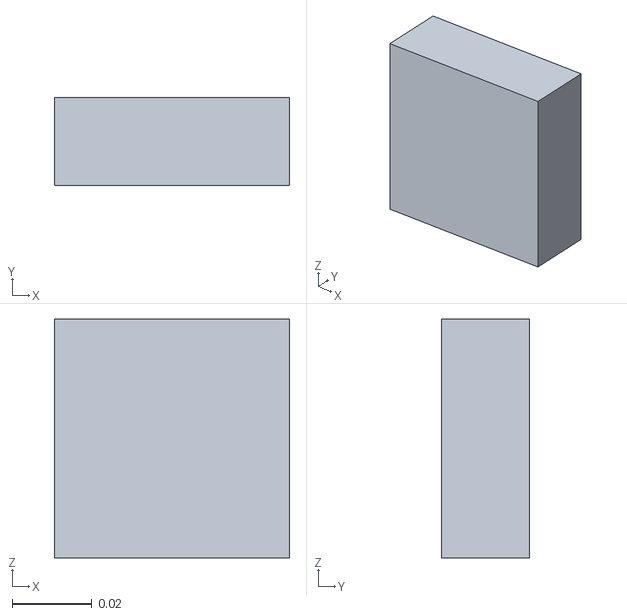
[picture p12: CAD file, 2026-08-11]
mujoco_kinematic_v1/meshes/collision_convex_m/link1/004_m01_c04_p01.stl
0.059 x 0.022 x 0.06

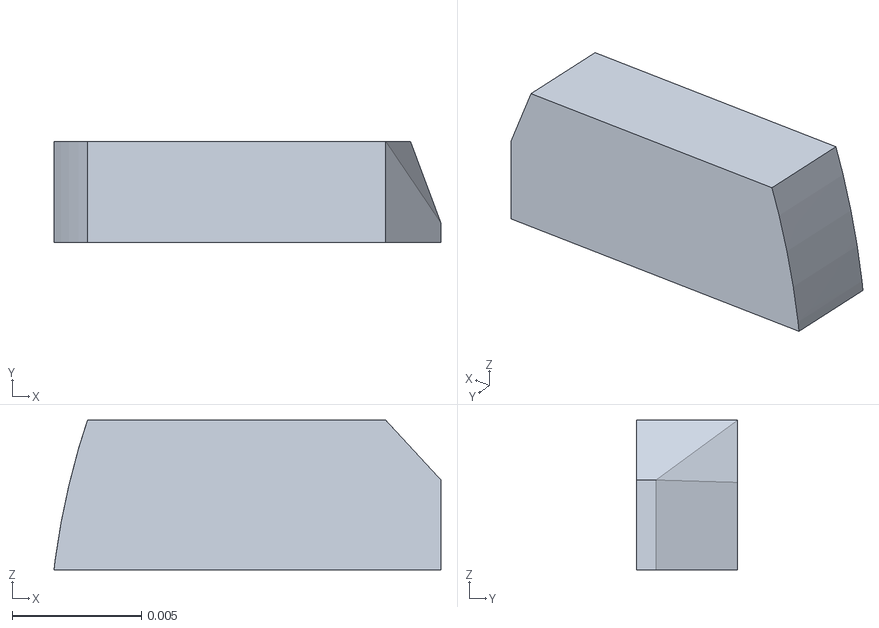
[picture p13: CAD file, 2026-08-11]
mujoco_kinematic_v1/meshes/collision_convex_m/link2/037_m02_c01_p01.stl
0.015 x 0.00392 x 0.0058

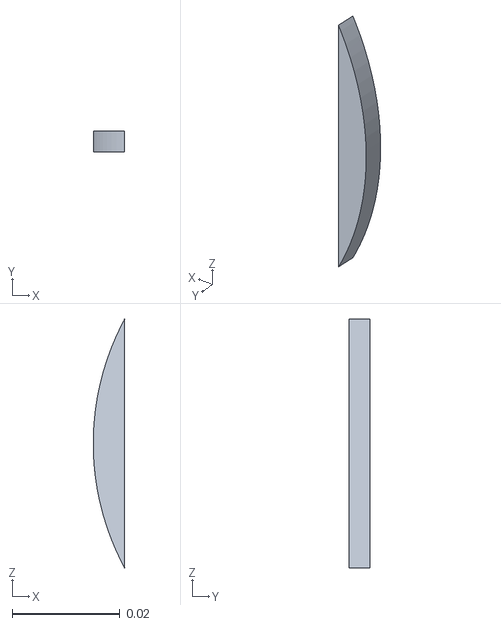
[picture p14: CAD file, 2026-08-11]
mujoco_kinematic_v1/meshes/collision_convex_m/link3/048_m02_c01_p45.stl
0.00582 x 0.00388 x 0.0461

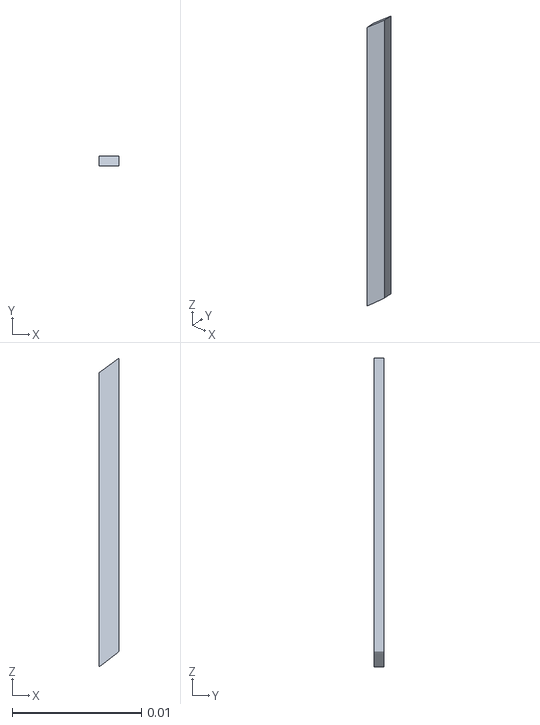
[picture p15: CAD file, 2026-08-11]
mujoco_kinematic_v1/meshes/collision_convex_m/link4/045_m01_c01_p45.stl
0.00157 x 0.000753 x 0.0239

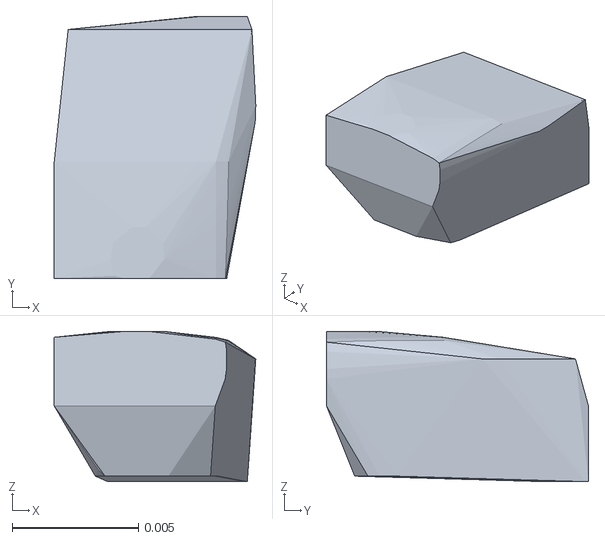
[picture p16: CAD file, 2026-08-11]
mujoco_kinematic_v1/meshes/collision_convex_m/link5/180_m03_c01_p53.stl
0.00799 x 0.0104 x 0.00595

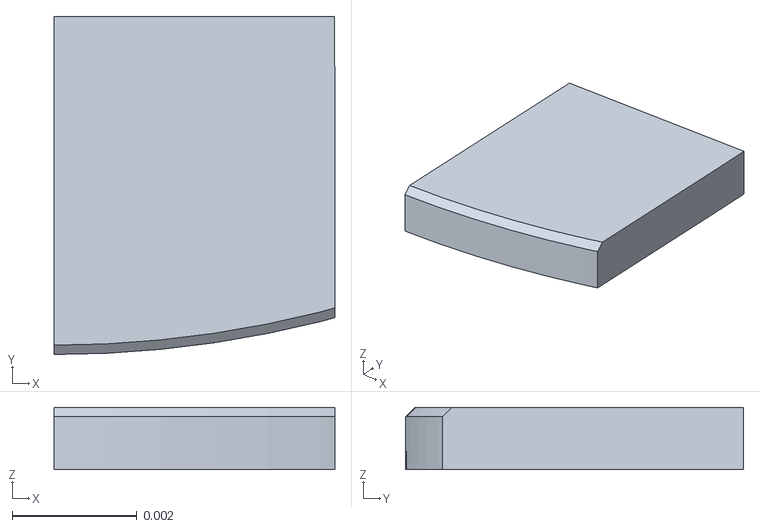
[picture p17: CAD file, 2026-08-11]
mujoco_kinematic_v1/meshes/collision_convex_m/link6/022_m01_c01_p22.stl
0.00449 x 0.00541 x 0.001

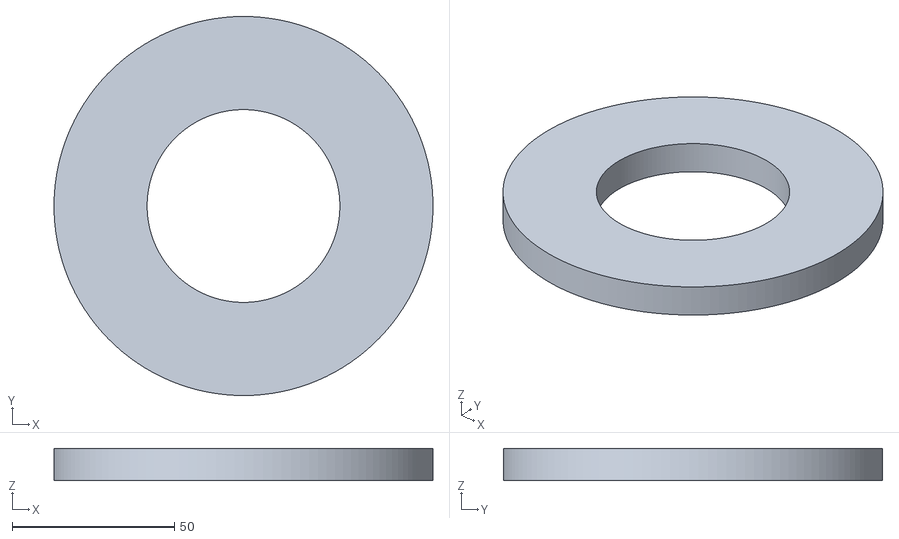
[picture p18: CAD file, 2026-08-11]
mujoco_kinematic_v1/meshes/collision_raw_mm/base_link/01_J1_Fixed_Collision_Proxy.stl
117.0 x 117.0 x 10.0

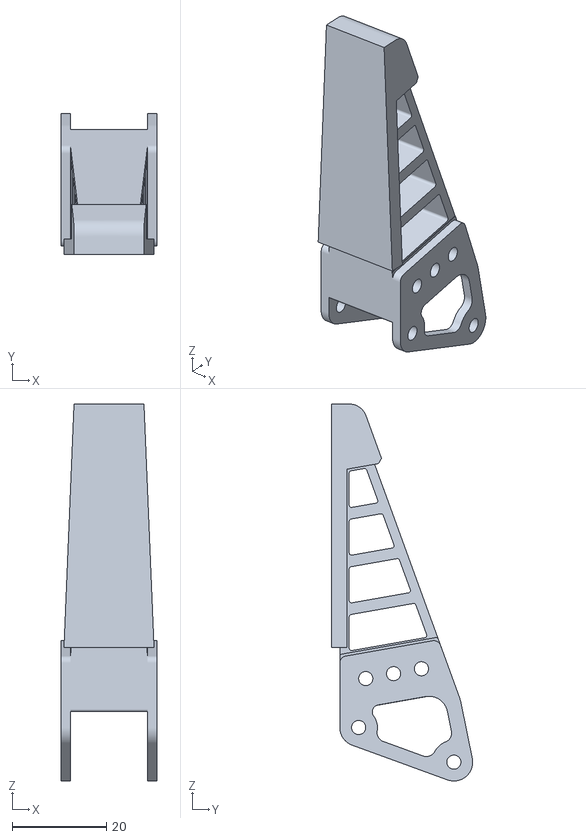
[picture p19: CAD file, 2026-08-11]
mujoco_kinematic_v1/meshes/collision_raw_mm/gripper/09_Gripper_Left_Finger.stl
20.4 x 30.0 x 80.0

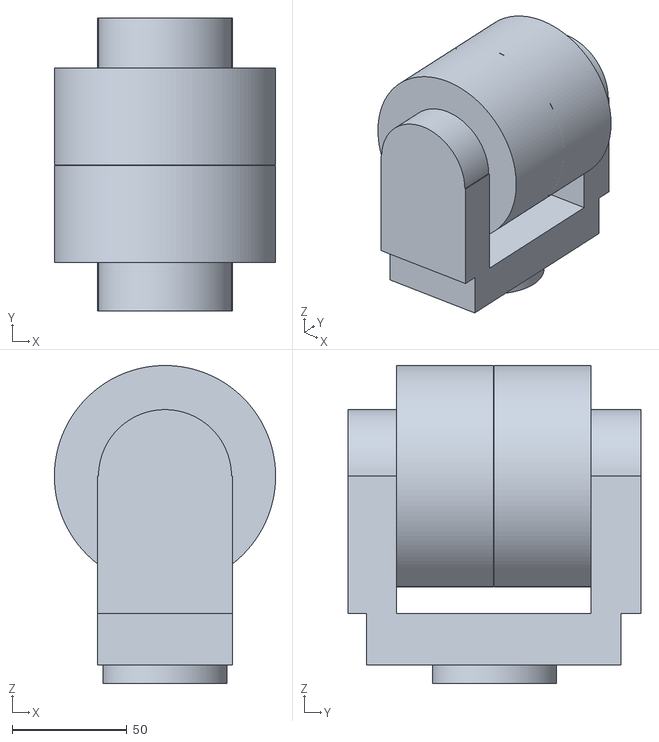
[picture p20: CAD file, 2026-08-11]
mujoco_kinematic_v1/meshes/collision_raw_mm/link1/01_J1_Moving_Collision_Proxy.stl
96.5 x 128.0 x 138.7

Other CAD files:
mujoco_kinematic_v1/meshes/collision_raw_mm/link2/02_J3_Output_Flange_Proxy.stl
mujoco_kinematic_v1/meshes/collision_raw_mm/link3/02_Forearm_Collision_Proxy.stl
mujoco_kinematic_v1/meshes/collision_raw_mm/link4/02_Wrist_Prelink_Collision_Proxy.stl
J6末端_相机上置机械零位_v15_13.stl
mujoco_kinematic_v1/meshes/collision_convex_m/base_link/001_m01_c01_p01.stl
mujoco_kinematic_v1/meshes/collision_convex_m/base_link/002_m01_c01_p02.stl
mujoco_kinematic_v1/meshes/collision_convex_m/base_link/003_m01_c01_p03.stl
mujoco_kinematic_v1/meshes/collision_convex_m/base_link/004_m01_c01_p04.stl
mujoco_kinematic_v1/meshes/collision_convex_m/base_link/005_m01_c01_p05.stl
mujoco_kinematic_v1/meshes/collision_convex_m/base_link/006_m01_c01_p06.stl
mujoco_kinematic_v1/meshes/collision_convex_m/base_link/008_m01_c01_p08.stl
mujoco_kinematic_v1/meshes/collision_convex_m/base_link/009_m01_c01_p09.stl
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

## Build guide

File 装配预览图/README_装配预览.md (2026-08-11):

# V15.13 装配预览

三张预览均由最终 FCStd 的世界位姿生成；刚性 Link 局部坐标导出仅用于 ROS2/MuJoCo，不再直接作为整机世界坐标渲染。J6=0° 时相机在上，连接件相对 DM-G6220 输出法兰的安装关系未改变，夹爪保持反转状态，未增加转接片。

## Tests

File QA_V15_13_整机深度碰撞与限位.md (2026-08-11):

# V15.13 整机深度碰撞与限位复核

状态：**PASS_WITH_COUPLED_COLLISION_GUARD_REQUIRED**

保存零位精确碰撞：`False`；检查碰撞对 `231` 组。
采样姿态：`503`；进入 VTK 三角面窄相位的碰撞对测试：`14860`。

| 类别 | 姿态数 | 无碰撞 | 记录的碰撞姿态数 |
|---|---:|---:|---:|
| independent_J1_representative_full_turn | 37 | True | 0 |
| independent_J2 | 35 | True | 0 |
| independent_J3 | 35 | True | 0 |
| independent_J4 | 56 | True | 0 |
| independent_J5 | 46 | True | 0 |
| independent_J6 | 73 | True | 0 |
| coupled_J5_J6_grid | 39 | True | 0 |
| coupled_limit_corners | 32 | True | 0 |
| coupled_random_seed_1513 | 150 | False | 5 |

## 限位解释

- J2～J6 的位置限位已写入 FreeCAD、ROS2/MoveIt 与 MuJoCo 契约；J6 为 `-180°～+180°`，相机上置姿态是 `0°`。
- 独立关节扫描用于确认单轴范围；多轴联合空间不是矩形安全域，若联合采样中出现碰撞，运行时连续碰撞守卫和 MoveIt 自碰撞规划必须启用，不能靠缩成一组随意猜测的独立角度解决。
- J1 几何上保持 continuous；实机电缆未建模，未测得电缆可承受圈数前不得允许累计无限旋转。
- 速度、力矩、质量、质心和惯量没有实测数据，本工程明确留空，没有猜填。

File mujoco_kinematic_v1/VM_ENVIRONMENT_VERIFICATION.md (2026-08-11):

# Ubuntu 22.04 VM 环境核验

核验主机：`codex@192.168.11.130`，系统：Ubuntu 22.04，主机名：`ubuntu22-vm`。

- ROS 2 Humble：已安装，`ROS_VERSION=2`、`ROS_DISTRO=humble`；
- ROS 包约 380 个，含 `ros-humble-desktop`、RViz2、Gazebo、`robot_state_publisher`、`joint_state_publisher`；
- ROS 2 Control：`controller_manager`、`joint_trajectory_controller` 已安装；
- Xacro、colcon：已安装；
- MoveIt 2：`moveit_ros_move_group` 与 `moveit_setup_assistant` 当前未安装；
- MuJoCo 环境：`/home/codex/mujoco_arm_env`，版本 `3.11.0`；
- 本次补充：`trimesh 4.7.4`、`coacd 1.0.11`、`fast-simplification 0.1.12`、`networkx 3.4.2`；
- Pillow 已恢复到 VM 原有的 `12.3.0`；
- 图形：`DISPLAY=:1`，VMware SVGA3D，OpenGL core 4.1，直接渲染可用。

VM 工程路径：`/home/codex/projects/mujoco_kinematic_v1`。

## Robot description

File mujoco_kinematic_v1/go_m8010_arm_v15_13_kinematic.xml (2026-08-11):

<?xml version='1.0' encoding='utf-8'?>
<mujoco model="go_m8010_arm_v15_13_kinematic">
  <compiler angle="radian" autolimits="true" fusestatic="false" discardvisual="false" meshdir="." />
  <option gravity="0 0 0" timestep="0.002" integrator="implicitfast" />
  <size njmax="4000" nconmax="2000" />
  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
  <worldbody>
    <light pos="0 -1.2 1.8" dir="0 0.4 -1" directional="true" />
    <camera name="overview" pos="1.1 -1.1 0.8" xyaxes="0.707 0.707 0 -0.35 0.35 0.866" />
    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
    <body name="base_link" pos="0 0 0" quat="1 0 0 0">
      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
      <body name="link1" pos="0 0 0" quat="1 0 0 0">
        <joint name="J1" type="hinge" pos="0 0 0" axis="0 -2.77555756156289e-17 1" ref="0" limited="false" damping="0" frictionloss="0" armature="0" />
        <inertial pos="0 0 0" mass="1" diaginertia="0.001 0.001 0.001" />
        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
        <body name="link2" pos="-1.19529999999846e-06 -0.000348645100000006 0.092639782" quat="1 0 0 0">
          <joint name="J2" type="hinge" pos="0 0 0" axis="0 1 -2.77555756156289e-17" ref="0" limited="true" damping="0" frictionloss="0" armature="0" range="-2.96705972839036 2.96705972839036" />
          <inertial pos="0 0 0" mass="1" diaginertia="0.001 0.001 0.001" />
          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
          <body name="link3" pos="-0.248601759363284 -0.0360000000000005 1.67815400527331e-05" quat="1 0 0 0">
            <joint name="J3" type="hinge" pos="0 0 0" axis="0 1 -2.77555756156289e-17" ref="0" limited="true" damping="0" frictionloss="0" armature="0" range="-2.96705972839036 2.96705972839036" />
            <inertial pos="0 0 0" mass="1" diaginertia="0.001 0.001 0.001" />
            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
            <body name="link4" pos="-0.202346021849608 -3.6969356019974e-17 0.0519614239654557" quat="0.713339230184703 -9.55511142539512e-18 -0.70081890862012 1.33415802272334e-13">
              <joint name="J4" type="hinge" pos="0 0 0" axis="3.80682902749686e-13 1 -4.91432301547264e-19" ref="0" limited="true" damping="0" frictionloss="0" armature="0" range="-2.02458193231342 2.77507351067098" />
              <inertial pos="0 0 0" mass="1" diaginertia="0.001 0.001 0.001" />
              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
              <body name="link5" pos="0.00930000012983338 0.0320000209058991 0.097898948000751" quat="0.913547809067383 -0.406731361648183 -4.35751695212161e-14 1.04177060842146e-13">
                <joint name="J5" type="hinge" pos="0 0 0" axis="1 0 -1.59232002583387e-13" ref="0" limited="true" damping="0" frictionloss="0" armature="0" range="-1.232202451908 2.63893782901543" />
                <inertial pos="0 0 0" mass="1" diaginertia="0.001 0.001 0.001" />
                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
                <body name="link6" pos="-0.0109991955299831 -0.000147148457748934 0.0995275274114727" quat="5.55111512312578e-17 0 -5.55111512312578e-17 1">
                  <joint name="J6" type="hinge" pos="0 0 0" axis="-1.59232002583387e-13 6.09321620936853e-17 1" ref="0" limited="true" damping="0" frictionloss="0" armature="0" range="-3.14159265358979 3.14159265358979" />
                  <inertial pos="0 0 0" mass="1" diaginertia="0.001 0.001 0.001" />
                  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
                  <body name="gripper" pos="0 0 0" quat="1 0 0 0">
                    <inertial pos="0 0 0" mass="1" diaginertia="0.001 0.001 0.001" />
                    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
                  </body>
                </body>
              </body>
            </body>
          </body>
        </body>
      </body>
    </body>
  </worldbody>
</mujoco>

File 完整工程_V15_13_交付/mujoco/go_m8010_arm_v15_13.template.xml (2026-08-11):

<mujoco model="go_m8010_arm_v15_13">
  <compiler angle="radian" meshdir="../ros2_ws/src/go_m8010_arm_description/meshes" inertiafromgeom="false"/>
  <option gravity="0 0 -9.81"/>
  <default>
    <geom density="0" friction="__SLIDE_FRICTION__ __TORSIONAL_FRICTION__ __ROLLING_FRICTION__"/>
  </default>
  <asset>
    <mesh name="base_link_visual" file="visual/base_link.stl" scale="0.001 0.001 0.001"/>
    <mesh name="base_link_collision" file="collision/base_link.stl" scale="0.001 0.001 0.001"/>
    <mesh name="link1_visual" file="visual/link1.stl" scale="0.001 0.001 0.001"/>
    <mesh name="link1_collision" file="collision/link1.stl" scale="0.001 0.001 0.001"/>
    <mesh name="link2_visual" file="visual/link2.stl" scale="0.001 0.001 0.001"/>
    <mesh name="link2_collision" file="collision/link2.stl" scale="0.001 0.001 0.001"/>
    <mesh name="link3_visual" file="visual/link3.stl" scale="0.001 0.001 0.001"/>
    <mesh name="link3_collision" file="collision/link3.stl" scale="0.001 0.001 0.001"/>
    <mesh name="link4_visual" file="visual/link4.stl" scale="0.001 0.001 0.001"/>
    <mesh name="link4_collision" file="collision/link4.stl" scale="0.001 0.001 0.001"/>
    <mesh name="link5_visual" file="visual/link5.stl" scale="0.001 0.001 0.001"/>
    <mesh name="link5_collision" file="collision/link5.stl" scale="0.001 0.001 0.001"/>
    <mesh name="link6_visual" file="visual/link6.stl" scale="0.001 0.001 0.001"/>
    <mesh name="link6_collision" file="collision/link6.stl" scale="0.001 0.001 0.001"/>
    <mesh name="gripper_visual" file="visual/gripper.stl" scale="0.001 0.001 0.001"/>
    <mesh name="gripper_collision" file="collision/gripper.stl" scale="0.001 0.001 0.001"/>
  </asset>
  <worldbody>
    <body name="base_link" pos="0 0 0" quat="1 0 0 0">
      <geom name="base_link_visual" type="mesh" mesh="base_link_visual" contype="0" conaffinity="0" group="1" rgba="0.45 0.14 0.18 1"/>
      <geom name="base_link_collision" type="mesh" mesh="base_link_collision" contype="1" conaffinity="1" group="3" rgba="0.1 0.7 0.8 0.25"/>
      <body name="link1" pos="0 0 0" quat="1 0 0 0">
        <inertial pos="__LINK1_COM_X__ __LINK1_COM_Y__ __LINK1_COM_Z__" mass="__LINK1_MASS_KG__" fullinertia="__LINK1_IXX__ __LINK1_IYY__ __LINK1_IZZ__ __LINK1_IXY__ __LINK1_IXZ__ __LINK1_IYZ__"/>
        <joint name="J1" type="hinge" pos="0 0 0" axis="0 -2.77555756156289e-17 1" ref="0" limited="false"/>
        <geom name="link1_visual" type="mesh" mesh="link1_visual" contype="0" conaffinity="0" group="1" rgba="0.45 0.14 0.18 1"/>
        <geom name="link1_collision" type="mesh" mesh="link1_collision" contype="1" conaffinity="1" group="3" rgba="0.1 0.7 0.8 0.25"/>
        <body name="link2" pos="-1.19529999999846e-06 -0.000348645100000006 0.092639782" quat="1 0 0 0">
          <inertial pos="__LINK2_COM_X__ __LINK2_COM_Y__ __LINK2_COM_Z__" mass="__LINK2_MASS_KG__" fullinertia="__LINK2_IXX__ __LINK2_IYY__ __LINK2_IZZ__ __LINK2_IXY__ __LINK2_IXZ__ __LINK2_IYZ__"/>
          <joint name="J2" type="hinge" pos="0 0 0" axis="0 1 -2.77555756156289e-17" ref="0" limited="true" range="-2.96705972839036 2.96705972839036"/>
          <geom name="link2_visual" type="mesh" mesh="link2_visual" contype="0" conaffinity="0" group="1" rgba="0.45 0.14 0.18 1"/>
          <geom name="link2_collision" type="mesh" mesh="link2_collision" contype="1" conaffinity="1" group="3" rgba="0.1 0.7 0.8 0.25"/>
          <body name="link3" pos="-0.248601759363284 -0.0360000000000005 1.67815400527331e-05" quat="1 0 0 0">
            <inertial pos="__LINK3_COM_X__ __LINK3_COM_Y__ __LINK3_COM_Z__" mass="__LINK3_MASS_KG__" fullinertia="__LINK3_IXX__ __LINK3_IYY__ __LINK3_IZZ__ __LINK3_IXY__ __LINK3_IXZ__ __LINK3_IYZ__"/>
            <joint name="J3" type="hinge" pos="0 0 0" axis="0 1 -2.77555756156289e-17" ref="0" limited="true" range="-2.96705972839036 2.96705972839036"/>
            <geom name="link3_visual" type="mesh" mesh="link3_visual" contype="0" conaffinity="0" group="1" rgba="0.45 0.14 0.18 1"/>
            <geom name="link3_collision" type="mesh" mesh="link3_collision" contype="1" conaffinity="1" group="3" rgba="0.1 0.7 0.8 0.25"/>
            <body name="link4" pos="-0.202346021849608 -3.6969356019974e-17 0.0519614239654557" quat="0.713339230184703 -9.55511142539512e-18 -0.70081890862012 1.33415802272334e-13">
              <inertial pos="__LINK4_COM_X__ __LINK4_COM_Y__ __LINK4_COM_Z__" mass="__LINK4_MASS_KG__" fullinertia="__LINK4_IXX__ __LINK4_IYY__ __LINK4_IZZ__ __LINK4_IXY__ __LINK4_IXZ__ __LINK4_IYZ__"/>
              <joint name="J4" type="hinge" pos="0 0 0" axis="3.80682902749686e-13 1 -4.91432301547264e-19" ref="0" limited="true" range="-2.02458193231342 2.77507351067098"/>
              <geom name="link4_visual" type="mesh" mesh="link4_visual" contype="0" conaffinity="0" group="1" rgba="0.45 0.14 0.18 1"/>
              <geom name="link4_collision" type="mesh" mesh="link4_collision" contype="1" conaffinity="1" group="3" rgba="0.1 0.7 0.8 0.25"/>
              <body name="link5" pos="0.00930000012983338 0.0320000209058991 0.097898948000751" quat="0.913547809067383 -0.406731361648183 -4.35751695212161e-14 1.04177060842146e-13">
                <inertial pos="__LINK5_COM_X__ __LINK5_COM_Y__ __LINK5_COM_Z__" mass="__LINK5_MASS_KG__" fullinertia="__LINK5_IXX__ __LINK5_IYY__ __LINK5_IZZ__ __LINK5_IXY__ __LINK5_IXZ__ __LINK5_IYZ__"/>
                <joint name="J5" type="hinge" pos="0 0 0" axis="1 0 -1.59232002583387e-13" ref="0" limited="true" range="-1.232202451908 2.63893782901543"/>
                <geom name="link5_visual" type="mesh" mesh="link5_visual" contype="0" conaffinity="0" group="1" rgba="0.45 0.14 0.18 1"/>
                <geom name="link5_collision" type="mesh" mesh="link5_collision" contype="1" conaffinity="1" group="3" rgba="0.1 0.7 0.8 0.25"/>
                <body name="link6" pos="-0.0109991955299831 -0.000147148457748934 0.0995275274114727" quat="5.55111512312578e-17 0 -5.55111512312578e-17 1">
                  <inertial pos="__LINK6_COM_X__ __LINK6_COM_Y__ __LINK6_COM_Z__" mass="__LINK6_MASS_KG__" fullinertia="__LINK6_IXX__ __LINK6_IYY__ __LINK6_IZZ__ __LINK6_IXY__ __LINK6_IXZ__ __LINK6_IYZ__"/>
                  <joint name="J6" type="hinge" pos="0 0 0" axis="-1.59232002583387e-13 6.09321620936853e-17 1" ref="0" limited="true" range="-3.14159265358979 3.14159265358979"/>
                  <geom name="link6_visual" type="mesh" mesh="link6_visual" contype="0" conaffinity="0" group="1" rgba="0.45 0.14 0.18 1"/>
                  <geom name="link6_collision" type="mesh" mesh="link6_collision" contype="1" conaffinity="1" group="3" rgba="0.1 0.7 0.8 0.25"/>
                  <body name="gripper" pos="0 0 0" quat="1 0 0 0">
                    <inertial pos="__GRIPPER_COM_X__ __GRIPPER_COM_Y__ __GRIPPER_COM_Z__" mass="__GRIPPER_MASS_KG__" fullinertia="__GRIPPER_IXX__ __GRIPPER_IYY__ __GRIPPER_IZZ__ __GRIPPER_IXY__ __GRIPPER_IXZ__ __GRIPPER_IYZ__"/>
                    <geom name="gripper_visual" type="mesh" mesh="gripper_visual" contype="0" conaffinity="0" group="1" rgba="0.45 0.14 0.18 1"/>
                    <geom name="gripper_collision" type="mesh" mesh="gripper_collision" contype="1" conaffinity="1" group="3" rgba="0.1 0.7 0.8 0.25"/>
                  </body>
                </body>
              </body>
            </body>
          </body>
        </body>
      </body>
    </body>
  </worldbody>
</mujoco>

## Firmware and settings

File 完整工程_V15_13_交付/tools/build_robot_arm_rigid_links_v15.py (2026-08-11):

from __future__ import annotations

"""Build reproducible rigid-link assets from the measured-axis V15 assembly.

This is deliberately a non-reparenting export.  The accepted V15 assembly is
opened read-only in spirit, new local-frame reference objects are added to a
derived FCStd copy, and every mesh is exported in its owning link frame.

The three complete GO-M8010-6 display objects at J1/J2 are not welded into a
single parent link.  They are split by the audited V4 STEP solid-index rule:

    output rotor: solids 24-30, 32, 34
    neutral B6808 display: solid 31 (visual only, no collision/mass)
    stator: all remaining solids

No screw, washer, bearing or bracket becomes an independent URDF link.
"""

import csv
import hashlib
import json
import math
from datetime import datetime, timezone
from pathlib import Path

import FreeCAD as App
import Mesh
import MeshPart
import Part


WORKSPACE = Path(__file__).resolve().parent
SOURCE_ROOT = Path(r"D:\AI_JIXIEBI\模型\机械臂完整装配_真实关节轴_v15")
SOURCE_FCSTD = SOURCE_ROOT / "机械臂完整装配_六轴_真实关节轴_v15.FCStd"
SOURCE_AXES_JSON = SOURCE_ROOT / "V15_真实关节轴定义.json"

OUTPUT_ROOT = SOURCE_ROOT / "rigid_links_v15"
VISUAL_DIR = OUTPUT_ROOT / "visual"
COLLISION_DIR = OUTPUT_ROOT / "collision"
GRIPPER_INTERNAL_DIR = OUTPUT_ROOT / "gripper_internal_zero_reference"
ROS2_DIR = OUTPUT_ROOT / "ros2"
MUJOCO_DIR = OUTPUT_ROOT / "mujoco"
OUTPUT_FCSTD = SOURCE_ROOT / "机械臂完整装配_六轴_刚性Link拆分_v15.FCStd"
MANIFEST_JSON = OUTPUT_ROOT / "rigid_link_manifest.json"
MEMBERSHIP_CSV = OUTPUT_ROOT / "rigid_link_membership.csv"
QA_JSON = OUTPUT_ROOT / "qa_rigid_link_export.json"
README_MD = OUTPUT_ROOT / "README.md"

OUTPUT_SOLID_INDICES = {24, 25, 26, 27, 28, 29, 30, 32, 34}
NEUTRAL_SOLID_INDICES = {31}
OUTPUT_COLLISION_SOLID_INDICES = OUTPUT_SOLID_INDICES - {32}
EXPECTED_GO_M8010_SOLID_COUNT = 34

LINEAR_DEFLECTION_VISUAL_MM = 0.20
LINEAR_DEFLECTION_COLLISION_MM = 0.35
ANGULAR_DEFLECTION_RAD = 0.20
MESH_SCALE_TO_M = [0.001, 0.001, 0.001]


def sha256(path: Path) -> str:
    digest = hashlib.sha256()
    with path.open("rb") as stream:
        for block in iter(lambda: stream.read(1024 * 1024), b""):
            digest.update(block)
    return digest.hexdigest().upper()


def numbered(prefix: str, count: int) -> list[str]:
    return [f"{prefix}{index:02d}" for index in range(1, count + 1)]


def placement_from_frame(frame: dict) -> App.Placement:
    x = frame["x_axis_world_at_zero"]
    y = frame["y_axis_world_at_zero"]
    z = frame["z_axis_world_at_zero"]
    origin = frame["origin_world_mm"]
    matrix = App.Matrix()
    matrix.A11, matrix.A12, matrix.A13 = x[0], y[0], z[0]
    matrix.A21, matrix.A22, matrix.A23 = x[1], y[1], z[1]
    matrix.A31, matrix.A32, matrix.A33 = x[2], y[2], z[2]
    rotation = App.Rotation(matrix)
    return App.Placement(App.Vector(*origin), rotation)


def rotation_matrix_from_frame(frame: dict) -> list[list[float]]:
    x = frame["x_axis_world_at_zero"]
    y = frame["y_axis_world_at_zero"]
    z = frame["z_axis_world_at_zero"]
    return [
        [x[0], y[0], z[0]],
        [x[1], y[1], z[1]],
        [x[2], y[2], z[2]],
    ]


def matrix_to_rpy(matrix: list[list[float]]) -> list[float]:
    sy = math.sqrt(matrix[0][0] ** 2 + matrix[1][0] ** 2)
    singular = sy < 1.0e-12
    if not singular:
        roll = math.atan2(matrix[2][1], matrix[2][2])
        pitch = math.atan2(-matrix[2][0], sy)
        yaw = math.atan2(matrix[1][0], matrix[0][0])
    else:
        roll = math.atan2(-matrix[1][2], matrix[1][1])
        pitch = math.atan2(-matrix[2][0], sy)
        yaw = 0.0
    return [roll, pitch, yaw]


def relative_placement(frame_world: App.Placement, object_world: App.Placement) -> App.Placement:
    return frame_world.inverse().multiply(object_world)


def local_part_shape(obj, frame_world: App.Placement) -> Part.Shape:
    shape = obj.Shape.copy()
    shape.Placement = relative_placement(frame_world, obj.getGlobalPlacement())
    return shape


def local_mesh(obj, frame_world: App.Placement) -> Mesh.Mesh:
    mesh = Mesh.Mesh(obj.Mesh)
    mesh.Placement = relative_placement(frame_world, obj.getGlobalPlacement())
    return mesh


def motor_component_shape(
    motor_obj,
    component: str,
    frame_world: App.Placement,
) -> Part.Shape:
    source = motor_obj.Shape.copy()
    source.Placement = App.Placement()
    solids = list(source.Solids)
    if len(solids) != EXPECTED_GO_M8010_SOLID_COUNT:
        raise RuntimeError(
            f"{motor_obj.Name}: expected {EXPECTED_GO_M8010_SOLID_COUNT} STEP solids, "
            f"found {len(solids)}"
        )
    if component == "output":
        indices = OUTPUT_SOLID_INDICES
    elif component == "output_collision":
        indices = OUTPUT_COLLISION_SOLID_INDICES
    elif component == "neutral":
        indices = NEUTRAL_SOLID_INDICES
    elif component == "stator":
        indices = set(range(1, len(solids) + 1)) - OUTPUT_SOLID_INDICES - NEUTRAL_SOLID_INDICES
    else:
        raise ValueError(f"unknown motor component: {component}")
    selected = [solid.copy() for index, solid in enumerate(solids, 1) if index in indices]
    if len(selected) != len(indices):
        raise RuntimeError(f"{motor_obj.Name}: incomplete {component} split")
    compound = Part.makeCompound(selected)
    compound.Placement = relative_placement(frame_world, motor_obj.getGlobalPlacement())
    return compound


def part_shape_to_mesh(shape: Part.Shape, linear_deflection_mm: float) -> Mesh.Mesh:
    return MeshPart.meshFromShape(
        Shape=shape,
        LinearDeflection=linear_deflection_mm,
        AngularDeflection=ANGULAR_DEFLECTION_RAD,
        Relative=False,
    )


def build_combined_mesh(doc, specs: list[dict], frame_world: App.Placement, deflection: float) -> Mesh.Mesh:
    result = Mesh.Mesh()
    for spec in specs:
        if spec["kind"] == "object":
            obj = doc.getObject(spec["object"])
            if obj is None:
                raise RuntimeError(f"missing source object: {spec['object']}")
            if hasattr(obj, "Mesh"):
                piece = local_mesh(obj, frame_world)
            elif hasattr(obj, "Shape") and not obj.Shape.isNull():
                piece = part_shape_to_mesh(local_part_shape(obj, frame_world), deflection)
            else:
                raise RuntimeError(f"{obj.Name} has no exportable geometry")
        elif spec["kind"] == "motor_component":
            motor = doc.getObject(spec["object"])
            if motor is None:
                raise RuntimeError(f"missing source motor: {spec['object']}")
            piece = part_shape_to_mesh(
                motor_component_shape(motor, spec["component"], frame_world),
                deflection,
            )
        else:
            raise ValueError(spec["kind"])
        result.addMesh(piece)
    if result.CountFacets == 0:
        raise RuntimeError("empty combined mesh")
    return result


def build_collision_compound(doc, specs: list[dict], frame_world: App.Placement) -> Part.Shape:
    shapes: list[Part.Shape] = []
    for spec in specs:
        if spec["kind"] == "object":
            obj = doc.getObject(spec["object"])
            if obj is None or not hasattr(obj, "Shape") or obj.Shape.isNull():
                raise RuntimeError(f"missing collision BRep: {spec['object']}")
            shapes.append(local_part_shape(obj, frame_world))
        elif spec["kind"] == "motor_component":
            motor = doc.getObject(spec["object"])
            if motor is None:
                raise RuntimeError(f"missing source motor: {spec['object']}")
            shapes.append(motor_component_shape(motor, spec["component"], frame_world))
        else:
            raise ValueError(spec["kind"])
    compound = Part.makeCompound(shapes)
    if compound.isNull():
        raise RuntimeError("empty collision compound")
    return compound


def object_spec(name: str) -> dict:
    return {"kind": "object", "object": name, "token": name}


def motor_spec(source_object: str, actuator: str, component: str) -> dict:
    return {
        "kind": "motor_component",
        "object": source_object,
        "component": component,
        "actuator": actuator,
        "token": f"derived:{actuator}_GO_M8010_{component}",
    }


def specs_from_names(names: list[str]) -> list[dict]:
    return [object_spec(name) for name in names]


BASE_VISUAL = specs_from_names(["Support_Foot", "Upper_Base"]) + [
    motor_spec("Joint_Motor_GO_M8010_6", "J1", "stator")
]
BASE_COLLISION = specs_from_names(["Support_Foot", "Upper_Base", "J1_Fixed_Collision_Proxy"]) + [
    motor_spec("Joint_Motor_GO_M8010_6", "J1", "stator")
]

LINK1_HARDWARE = (
    numbered("M4_Screw_", 6)
    + numbered("J2_Left_M4x30_Screw_", 6)
    + numbered("J2_Left_M4_Washer_", 6)
    + numbered("J2_Right_M4x30_Screw_", 6)
    + numbered("J2_Right_M4_Washer_", 6)
)
LINK1_VISUAL = specs_from_names(
    ["J1_Axial_Compensation_Spacer", "V6_Shoulder_Official_M4"] + LINK1_HARDWARE
) + [
    motor_spec("Joint_Motor_GO_M8010_6", "J1", "output"),
    motor_spec("Joint_Motor_GO_M8010_6", "J1", "neutral"),
    motor_spec("J2_Left_Joint_Motor_GO_M8010_6", "J2A", "stator"),
    motor_spec("J2_Right_Joint_Motor_GO_M8010_6", "J2B", "stator"),
]
LINK1_COLLISION = specs_from_names(
    ["J1_Moving_Collision_Proxy", "J1_Output_Rotor_Proxy"]
)

LINK2_HARDWARE = (
    numbered("UpperArm_M35_Bottom_", 3)
    + numbered("UpperArm_M35_Top_", 3)
    + numbered("J3_Output_M4_Screw_", 6)
)
LINK2_VISUAL = specs_from_names(
    [
        "UpperArm_A_SleeveSide_PrintPart",
        "UpperArm_B_Distal_PrintPart",
        "J3_Output_Rotor_STEP_Display",
        "J3_B6808_Bearing_Neutral_STEP_Display",
    ]
    + LINK2_HARDWARE
) + [
    motor_spec("J2_Left_Joint_Motor_GO_M8010_6", "J2A", "output"),
    motor_spec("J2_Left_Joint_Motor_GO_M8010_6", "J2A", "neutral"),
    motor_spec("J2_Right_Joint_Motor_GO_M8010_6", "J2B", "output"),
    motor_spec("J2_Right_Joint_Motor_GO_M8010_6", "J2B", "neutral"),
]
LINK2_COLLISION = specs_from_names(
    ["UpperArm_Full_Collision_Proxy", "J3_Output_Flange_Proxy"]
) + [
    motor_spec("J2_Left_Joint_Motor_GO_M8010_6", "J2A", "output_collision"),
    motor_spec("J2_Right_Joint_Motor_GO_M8010_6", "J2B", "output_collision"),
]

LINK3_HARDWARE = numbered("Forearm_J3_M35_Screw_", 6) + numbered(
    "Forearm_J4_M35_Screw_", 6
)
LINK3_VISUAL = specs_from_names(
    [
        "J3_Motor_Stator_STEP_Display",
        "Forearm_v3_HighDetail_Display",
        "J4_Motor_Stator_STEP_Display",
    ]
    + LINK3_HARDWARE
)
LINK3_COLLISION = specs_from_names(
    [
        "J3_Motor_Stator_Collision_Proxy",
        "Forearm_Collision_Proxy",
        "J4_Motor_Stator_Collision_Proxy",
    ]
)

LINK4_HARDWARE = numbered("J4_Output_M4_Screw_", 6) + numbered(
    "Wrist_Prelink_J5_M35_Screw_", 6
)
LINK4_VISUAL = specs_from_names(
    [
        "J4_Output_Rotor_STEP_Display",
        "J4_B6808_Bearing_Neutral_STEP_Display",
        "Wrist_Prelink_v1_HighDetail_Display",
        "J5_Motor_Stator_STEP_Display",
    ]
    + LINK4_HARDWARE
)
LINK4_COLLISION = specs_from_names(
    [
        "J4_Output_Flange_Collision_Proxy",
        "Wrist_Prelink_Collision_Proxy",
        "J5_Motor_Stator_Collision_Proxy",
    ]
)

LINK5_HARDWARE = numbered("Adapter_DM_G6220_M4x12_Screw_", 3)
LINK5_VISUAL = specs_from_names(
    [
        "J5_Output_Rotor_STEP_Display",
        "J5_B6808_Bearing_Neutral_STEP_Display",
        "J5_to_Damiao_J6_Adapter_STL_Display",
        "J6_DM_G6220_Stator_STEP_Display",
    ]
    + LINK5_HARDWARE
)
LINK5_COLLISION = specs_from_names(
    [
        "J5_Output_Flange_Collision_Proxy",
        "J5_to_Damiao_J6_Adapter_Collision_Proxy",
        "J6_DM_G6220_Stator_Collision_Proxy",
    ]
)

LINK6_VISUAL = specs_from_names(["J6_DM_G6220_Output_Rotor_STEP_Display"])
LINK6_COLLISION = specs_from_names(["J6_DM_G6220_Output_Rotor_Collision_Proxy"])

GRIPPER_STATIC_HARDWARE = (
    [f"Gripper_Hardware_{index:02d}" for index in (3, 4, 7, 8, 9, 10, 15, 16)]
    + numbered("DM_G6220_Connector_M4x8_Screw_", 6)
    + numbered("Gripper_Clevis_M3x16_Screw_", 2)
)
GRIPPER_VISUAL = specs_from_names(
    [
        "J6_Gripper_Connector_STEP_Display",
        "Gripper_Servo_STEP_Display",
        "Gripper_Fixed_Frame_STEP_Display",
    ]
    + GRIPPER_STATIC_HARDWARE
)
GRIPPER_COLLISION = specs_from_names(
    [
        "J6_Gripper_Connector_Collision_Proxy",
        "Gripper_Fixed_Frame_Collision_Proxy",
        "Gripper_Servo_Collision_Proxy",
    ]
)

GRIPPER_INTERNAL_ROLE_NAMES: dict[str, list[str]] = {
    "left_outer": ["Gripper_Left_Outer_Link"],
    "right_outer": ["Gripper_Right_Outer_Link"],
    "left_drive": ["Gripper_Left_Drive_Link"],
    "right_drive": ["Gripper_Right_Drive_Link"],
    "left_finger": [
        "Gripper_Left_Finger",
        *[f"Gripper_Hardware_{index:02d}" for index in (2, 5, 11, 13, 14)],
    ],
    "right_finger": [
        "Gripper_Right_Finger",
        *[f"Gripper_Hardware_{index:02d}" for index in (1, 6, 12, 17, 18, 19)],
    ],
}

LINK_SPECS: dict[str, dict] = {
    "base_link": {
        "source_group": "J1_Fixed_Rigid",
        "visual": BASE_VISUAL,
        "collision": BASE_COLLISION,
    },
    "link1": {
        "source_group": "J1_Moving_Rigid",
        "visual": LINK1_VISUAL,
        "collision": LINK1_COLLISION,
    },
    "link2": {
        "source_group": "J2_Driven_Reference_Rigid",
        "visual": LINK2_VISUAL,
        "collision": LINK2_COLLISION,
    },
    "link3": {
        "source_group": "J3_Driven_Rigid",
        "visual": LINK3_VISUAL,
        "collision": LINK3_COLLISION,
    },
    "link4": {
        "source_group": "J4_Driven_Rigid",
        "visual": LINK4_VISUAL,
        "collision": LINK4_COLLISION,
    },
    "link5": {
        "source_group": "J5_Driven_Rigid",
        "visual": LINK5_VISUAL,
        "collision": LINK5_COLLISION,
    },
    "link6": {
        "source_group": "J6_Driven_Rigid",
        "visual": LINK6_VISUAL,
        "collision": LINK6_COLLISION,
    },
    "gripper": {
        "source_group": "J6_Gripper_Assembly/static",
        "visual": GRIPPER_VISUAL,
        "collision": GRIPPER_COLLISION,
    },
}


def add_text(obj, name: str, group: str, value: str) -> None:
    obj.addProperty("App::PropertyString", name, group)
    setattr(obj, name, value)


def add_string_list(obj, name: str, group: str, values: list[str]) -> None:
    obj.addProperty("App::PropertyStringList", name, group)
    setattr(obj, name, values)


def add_float_list(obj, name: str, group: str, values: list[float]) -> None:
    obj.addProperty("App::PropertyFloatList", name, group)
    setattr(obj, name, values)


def spec_tokens(specs: list[dict]) -> list[str]:
    return [spec["token"] for spec in specs]


def source_object_names(specs: list[dict]) -> list[str]:
    return [spec["object"] for spec in specs if spec["kind"] == "object"]


def spec_rows(link: str, role: str, specs: list[dict]) -> list[dict]:
    rows = []
    for spec in specs:
        rows.append(
            {
                "owner": link,
                "geometry_role": role,
                "token": spec["token"],
                "source_object": spec["object"],
                "derivation": spec.get("component", "direct_object"),
                "urdf_link_count": 1,
            }
        )
    return rows


def mesh_bounds(mesh: Mesh.Mesh) -> dict:
    box = mesh.BoundBox
    return {
        "min_mm": [box.XMin, box.YMin, box.ZMin],
        "max_mm": [box.XMax, box.YMax, box.ZMax],
        "size_mm": [box.XLength, box.YLength, box.ZLength],
    }


def shape_bounds(shape: Part.Shape) -> dict:
    # BoundBox can reuse a stale triangulation cache and, for imported
    # multi-solid shapes with nested Placement, can effectively count the
    # top-level transform twice.  OCCT's optimal box is geometry-based and is
    # stable across FCStd save/reload.
    box = shape.optimalBoundingBox(False, False)
    return {
        "min_mm": [box.XMin, box.YMin, box.ZMin],
        "max_mm": [box.XMax, box.YMax, box.ZMax],
        "size_mm": [box.XLength, box.YLength, box.ZLength],
    }


def classify_unexported(doc, used_direct_names: set[str], split_sources: set[str]) -> list[dict]:
    group_names = [
        "J1_Fixed_Rigid",
        "J1_Moving_Rigid",
        "J2_Driven_Reference_Rigid",
        "J3_Driven_Rigid",
        "J4_Driven_Rigid",
        "J5_Driven_Rigid",
        "J6_Driven_Rigid",
        "J6_Gripper_Assembly",
    ]
    rows: list[dict] = []
    for group_name in group_names:
        group = doc.getObject(group_name)
        if group is None:
            raise RuntimeError(f"missing source group: {group_name}")
        for obj in group.Group:
            if obj.Name in used_direct_names:
                continue
            if obj.Name in split_sources:
                reason = "complete_motor_source_replaced_by_audited_BRep_solid_split"
            elif obj.TypeId == "App::Part":
                reason = "nested_assembly_classified_separately"
            elif not hasattr(obj, "Shape") and not hasattr(obj, "Mesh"):
                reason = "metadata_controller_or_joint_frame_no_exportable_geometry"
            else:
                reason = "reference_axis_envelope_witness_or_redundant_engineering_proxy"
            rows.append({"source_group": group_name, "object": obj.Name, "reason": reason})
    return rows


def validate_unique_visual_ownership() -> dict:
    direct_owner: dict[str, str] = {}
    duplicate_direct: list[dict] = []
    derived_owner: dict[str, str] = {}
    duplicate_derived: list[dict] = []
    for link, data in LINK_SPECS.items():
        for spec in data["visual"]:
            if spec["kind"] == "object":
                previous = direct_owner.setdefault(spec["object"], link)
                if previous != link:
                    duplicate_direct.append(
                        {"object": spec["object"], "first": previous, "second": link}
                    )
            else:
                previous = derived_owner.setdefault(spec["token"], link)
                if previous != link:
                    duplicate_derived.append(
                        {"component": spec["token"], "first": previous, "second": link}
                    )
    for role, names in GRIPPER_INTERNAL_ROLE_NAMES.items():
        owner = f"gripper_internal:{role}"
        for name in names:
            previous = direct_owner.setdefault(name, owner)
            if previous != owner:
                duplicate_direct.append({"object": name, "first": previous, "second": owner})
    if duplicate_direct or duplicate_derived:
        raise RuntimeError(
            f"duplicate visual rigid ownership: direct={duplicate_direct}, derived={duplicate_derived}"
        )
    return {
        "direct_object_owner": direct_owner,
        "derived_component_owner": derived_owner,
        "duplicate_direct": duplicate_direct,
        "duplicate_derived": duplicate_derived,
    }


def build_joint_tree(axis_data: dict) -> list[dict]:
    joints_by_name = {joint["name"]: joint for joint in axis_data["joints"]}
    source_keys = ["J1", "J2A", "J3", "J4", "J5", "J6"]
    output: list[dict] = []
    for source_key in source_keys:
        source = joints_by_name[source_key]
        name = "J2" if source_key == "J2A" else source_key
        record = {
            "name": name,
            "physical_actuators": ["J2A", "J2B"] if name == "J2" else [name],
            "parent_link": source["parent_link"],
            "child_link": source["child_link"],
            "joint_type_ros2": source["ros2_urdf"]["joint_type"],
            "axis_xyz_in_joint_frame": source["ros2_urdf"]["axis_xyz_in_joint_frame"],
            "origin_xyz_m": source["ros2_urdf"]["origin_xyz_m"],
            "origin_rpy_rad": source["ros2_urdf"]["origin_rpy_rad"],
            "position_limit_rad": source["ros2_urdf"]["position_limit_rad"],
            "mechanical_zero_deg": source["mechanical_zero_deg"],
            "velocity_limit_rad_s": source["ros2_urdf"]["velocity_limit_rad_s"],
            "effort_limit_nm": source["ros2_urdf"]["effort_limit_nm"],
            "mujoco": source["mujoco_mjcf"],
        }
        output.append(record)
    j6 = next(item for item in output if item["name"] == "J6")
    lower = j6["position_limit_rad"]["lower"]
    upper = j6["position_limit_rad"]["upper"]
    if abs(lower + math.pi) > 1.0e-12 or abs(upper - math.pi) > 1.0e-12:
        raise RuntimeError(f"J6 is not ±pi: {lower}, {upper}")
    output.append(
        {
            "name": "J6_to_gripper",
            "physical_actuators": [],
            "parent_link": "link6",
            "child_link": "gripper",
            "joint_type_ros2": "fixed",
            "axis_xyz_in_joint_frame": None,
            "origin_xyz_m": [0.0, 0.0, 0.0],
            "origin_rpy_rad": [0.0, 0.0, 0.0],
            "position_limit_rad": None,
            "mechanical_zero_deg": 0.0,
            "velocity_limit_rad_s": None,
            "effort_limit_nm": None,
            "mujoco": {
                "body_pos_m_in_parent": [0.0, 0.0, 0.0],
                "body_quat_wxyz_in_parent": [1.0, 0.0, 0.0, 0.0],
                "joint_type": "fixed_body_nesting",
            },
        }
    )
    return output


def write_membership_csv(rows: list[dict]) -> None:
    with MEMBERSHIP_CSV.open("w", encoding="utf-8-sig", newline="") as stream:
        writer = csv.DictWriter(
            stream,
            fieldnames=[
                "owner",
                "geometry_role",
                "token",
                "source_object",
                "derivation",
                "urdf_link_count",
            ],
        )
        writer.writeheader()
        writer.writerows(rows)
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
